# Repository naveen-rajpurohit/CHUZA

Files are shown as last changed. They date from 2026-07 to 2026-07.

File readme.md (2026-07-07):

<p align="center">
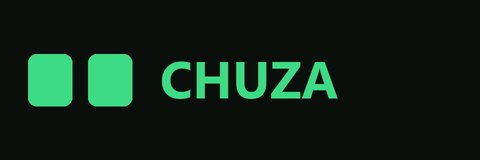
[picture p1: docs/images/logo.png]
CHUZA
  
</p>

<h3 align="center">An autonomous, internet-connected desktop companion robot</h3>

<p align="center">
  Built on an ESP32-S3 — animated OLED face, capacitive-touch reflexes, environmental sensing,<br>
  a globally-accessible FPV feed, and a custom desktop control app.
</p>

<p align="center">
  
  
  
  
</p>

---

CHUZA is more than an RC car — it's an autonomous desktop "pet" that wanders, reacts to petting, watches for the edge of the desk, and streams a live first-person video feed from anywhere in the world. This repo holds the full stack: the ESP32-S3 firmware, the wiring, and the companion desktop app used to drive it.

## Contents

- [Features](#features)
- [CHUZA Control (desktop app)](#chuza-control-desktop-app)
- [Architecture](#architecture)
- [Hardware & wiring](#hardware--wiring)
- [Tech stack](#tech-stack)
- [Getting started](#getting-started)
- [Repo structure](#repo-structure)
- [How it was built](#how-it-was-built)
- [License](#license)

## Features

- **Strictly non-blocking firmware.** `delay()` is banned throughout — a cooperative [`Scheduler`](lib/Scheduler/Scheduler.h) ticks every subsystem off `millis()`, so a slow network call can never make CHUZA miss a cliff edge.
- **Dual-core FreeRTOS split.** Core 0 owns WiFi, MQTT, and camera streaming; Core 1 owns motors, sensors, touch, and the display — heavy networking can never stall real-time control.
- **Animated RoboEyes-style face.** A mood engine on the SSD1306 OLED reacts to petting, battery level, and menu state (`lib/CHUZAFace`).
- **Capacitive touch gestures.** Single tap changes expression, triple tap opens the on-device menu — timing-based, debounced, tuned for the ESP32-S3's inverted touch polarity (`lib/CHUZATouch`).
- **Autonomous "Wander Mode".** Three intensities (OFF / SOFT / NORMAL) of idle-time exploration, instantly overridden by obstacle/cliff reflexes (`lib/CHUZAWander`).
- **Reflex safety.** Continuous VL53L0X polling for both forward obstacles and desk-edge "cliff" detection, clamped straight into the motor driver regardless of what's currently commanding it.
- **Dual connectivity, automatic failover.** A cloud path (TLS MQTT via HiveMQ) works from anywhere; the app auto-detects when it's on the same network as the robot and switches to a LAN-direct UDP + local MJPEG path for far lower latency (`lib/MqttLink`, `lib/CHUZALocalLink`).
- **Live FPV streaming.** The onboard OV2640 streams MJPEG over whichever transport is active, with a chip-thermal safety cutoff.
- **Persisted settings.** Every tunable (thresholds, PWM range, timers, per-subsystem enable/disable) lives in one `RobotSettings` model, editable from the app and saved to NVS.

## CHUZA Control (desktop app)

A Tkinter desktop app with a hand-rolled pixel-art "dark jungle" HUD — live telemetry, keyboard driving, and an in-app settings editor, all built directly on top of the same MQTT/UDP protocol the firmware speaks.

<table>
<tr>
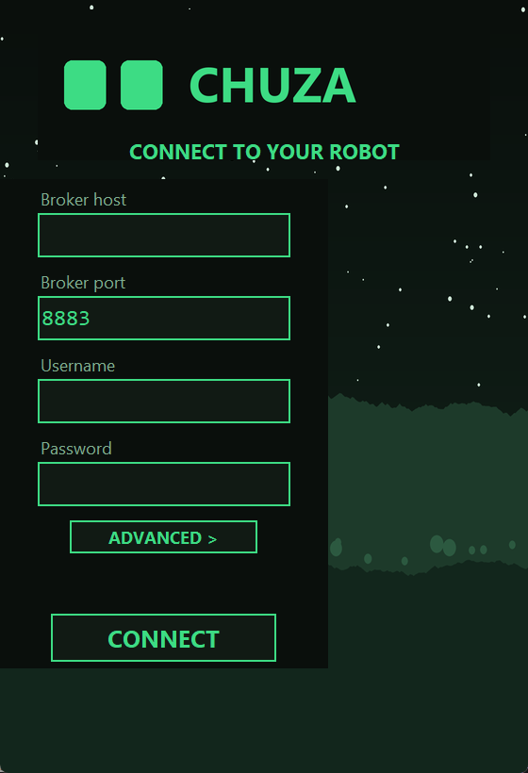
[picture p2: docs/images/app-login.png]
Login screen
<td align="center" width="50%"><br><sub>Connect screen — broker credentials, reused for in-app "Change Connection"</sub></td>
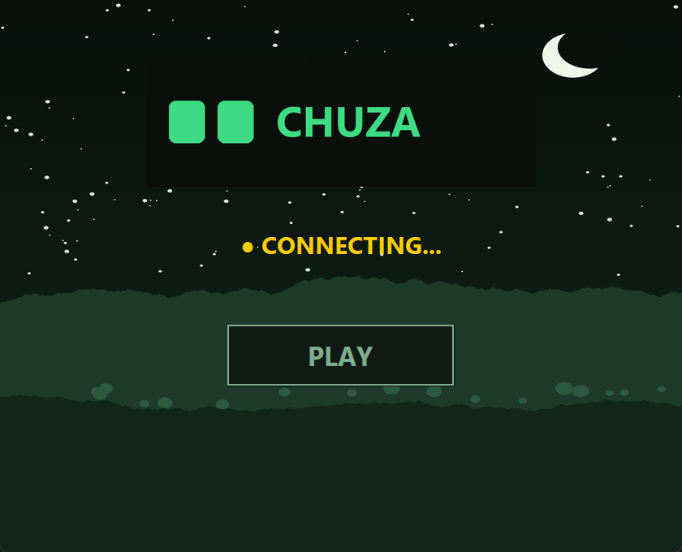
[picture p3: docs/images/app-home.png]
Home screen
<td align="center" width="50%"><br><sub>Home — live connection status, PLAY to enter driving mode</sub></td>
</tr>
<tr>
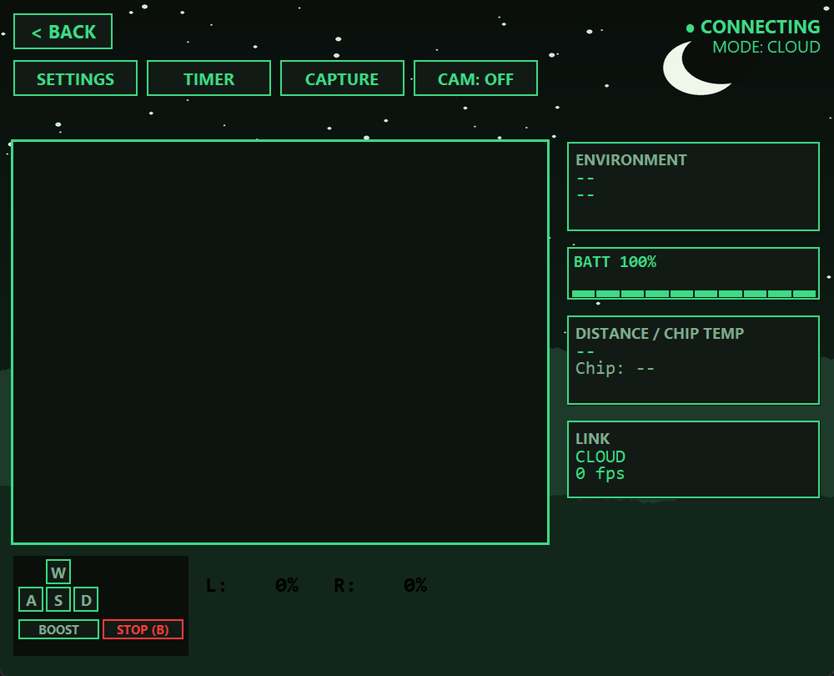
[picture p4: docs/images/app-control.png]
Control screen
<td align="center" width="50%"><br><sub>Control — camera viewport, D-pad readout, HUD telemetry sidebar</sub></td>
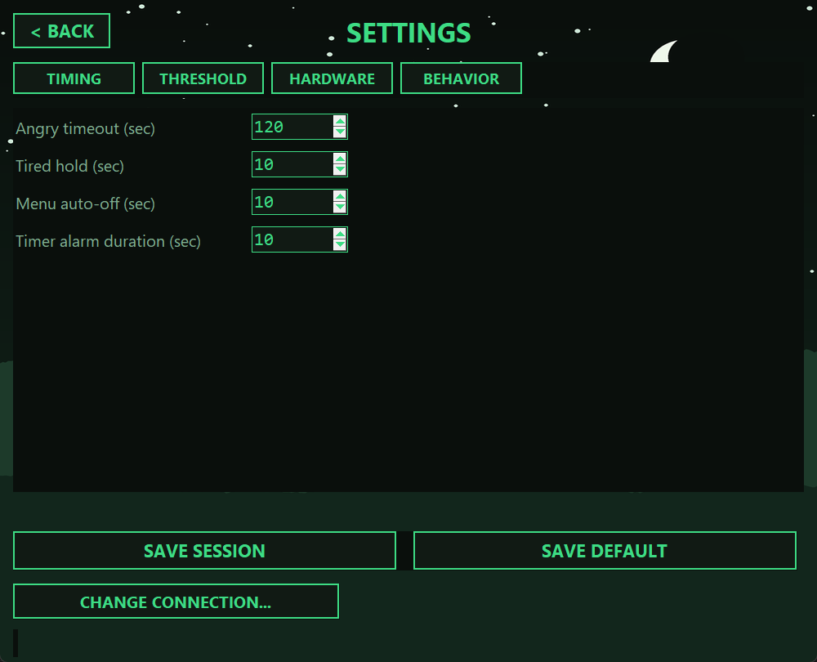
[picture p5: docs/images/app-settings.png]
Settings screen
<td align="center" width="50%"><br><sub>Settings — mirrors <code>RobotSettings</code> field-for-field, session or default save</sub></td>
</tr>
</table>

Driving uses **W/A/S/D** (Space to boost, B to brake), with gentle arc-turns while moving and pivot-turns while stationary. **CAPTURE** saves the current frame to disk; **TIMER** schedules an OLED alarm on the robot itself.

## Architecture

| Module | Responsibility |
|---|---|
| [`CHUZAWheels`](lib/CHUZAWheels) | DRV8833 motor driver — ramped speed targets, cliff-block clamp, per-side trim |
| [`CHUZAFace`](lib/CHUZAFace) | RoboEyes OLED face, mood engine, on-device menu state machine |
| [`CHUZATouch`](lib/CHUZATouch) | Debounced capacitive touch, single/double/triple-tap counting |
| [`CHUZABuzzer`](lib/CHUZABuzzer) | Non-blocking piezo melody/beep sequencer |
| [`CHUZAWander`](lib/CHUZAWander) | Autonomous idle-time driving policy (OFF/SOFT/NORMAL) |
| [`CHUZAEnvSense`](lib/CHUZAEnvSense) | BME280 temperature / humidity / pressure, cached reads |
| [`CHUZADistance`](lib/CHUZADistance) | VL53L0X time-of-flight ranging for obstacles + cliff edge |
| [`CHUZABattery`](lib/CHUZABattery) | Resistor-divider ADC read → 0–100% estimate |
| [`CHUZACamera`](lib/CHUZACamera) | OV2640 capture, enable/disable, thermal safety cutoff |
| [`CHUZASettings`](lib/CHUZASettings) | Single source of truth for every tunable, NVS persistence |
| [`MqttLink`](lib/MqttLink) | TLS MQTT over WiFi — two independent connections (commands, telemetry/camera) on Core 0 |
| [`CHUZALocalLink`](lib/CHUZALocalLink) | LAN-direct UDP commands + local MJPEG stream, always listening |
| [`CHUZACommand`](lib/CHUZACommand) | Single JSON command dispatcher shared by both MQTT and LAN-direct paths |
| [`Scheduler`](lib/Scheduler) | Minimal cooperative task scheduler driving the whole `loop()` |

**Command flow:** the app always tries LAN-direct UDP first; if that probe fails (different network, robot out of range), it transparently falls back to publishing on `robot/commands` over MQTT. Both paths route through the same `dispatchRobotCommand()`, so the robot behaves identically either way. Settings and timer commands are cloud-only, since the app's MQTT connection stays up regardless of link mode.

## Hardware & wiring

CHUZA wiring diagram

| Component | Role |
|---|---|
| Seeed XIAO ESP32S3 Sense | Main controller — dual-core ESP32-S3, WiFi, onboard OV2640 camera |
| DRV8833 | Dual H-bridge driver for the two drive motors |
| VL53L0X | Time-of-flight sensor — forward obstacles + downward cliff edge |
| BME280 | Temperature / humidity / pressure |
| SSD1306 (128×64, I2C) | Animated face / menu / clock display |
| Piezo buzzer | Non-blocking chirps and status tones |
| Capacitive touch pad | Petting input for the mood engine + menu access |
| LiPo cell + resistor divider | Power, with a halved-voltage tap into an ADC pin for battery %/voltage |

Pin assignments are centralized in [`include/CHUZAPins.h`](include/CHUZAPins.h) — nothing else in the codebase hardcodes a GPIO number. Two 3D-printed wheels (SolidWorks source + STL) live under [`Wheels/`](Wheels).

## Tech stack

**Firmware** — C++ / Arduino framework via PlatformIO, targeting `seeed_xiao_esp32s3`:
Adafruit BME280 / VL53L0X / SSD1306 / GFX / BusIO, PubSubClient, ArduinoJson.

**Desktop app** (`CHUZAControls/`) — Python 3, Tkinter for UI, `paho-mqtt` for the cloud link, Pillow for image handling, PyInstaller for standalone Windows builds.

## Getting started

### Firmware

1. Open the repo in [PlatformIO](https://platformio.org/) (VS Code extension or CLI).
2. Fill in your own values in [`include/Secrets.h`](include/Secrets.h) — WiFi credentials and a [HiveMQ Cloud](https://www.hivemq.com/mqtt-cloud-broker/) (or any TLS MQTT broker) host/username/password. The file is tracked as a template with placeholder values on purpose, so **never commit your real credentials over them**.
3. Build and upload to the `seeed_xiao_esp32s3` environment:
   ```
   pio run -t upload
   ```

### Desktop app

```
cd CHUZAControls
pip install -r requirements.txt
python app.py
```

On first launch, the login screen asks for the same broker host/username/password you put in `Secrets.h`. To build a standalone Windows executable instead, use the included `CHUZA Control.spec` with PyInstaller.

## Repo structure

```
CHUZA/
├── src/main.cpp            # setup()/loop() — wires every module together, owns the scheduler
├── include/CHUZAPins.h     # every GPIO assignment, in one place
├── include/Secrets.h       # WiFi + MQTT broker credentials (template — fill in your own)
├── lib/                    # one focused module per subsystem (see Architecture)
├── CHUZAControls/          # the Tkinter desktop control app
├── docs/images/            # README assets — screenshots, wiring diagram
└── Wheels/                 # 3D-printable wheel parts (SolidWorks + STL)
```

## How it was built

CHUZA V1 was built in six phases, each one only trusting the layer below it:

1. **Nervous system** — motor control, distance/cliff sensing, environmental sensing, non-blocking buzzer feedback.
2. **Face & touch** — animated OLED expressions, debounced capacitive tap timing, the on-device menu state machine.
3. **Brain** — fusing movement and UI into fully local, non-blocking autonomous behavior (Wander Mode + reflexes).
4. **Global communication** — NTP sync, TLS MQTT for bidirectional cloud control and telemetry.
5. **FPV streaming** — local MJPEG baseline first, then a LAN-direct UDP/HTTP path for low-latency same-network driving.
6. **Control hub** — the CHUZA Control desktop app, speaking the exact same command/telemetry protocol as the cloud and LAN paths.

## License

MIT — see [LICENSE](LICENSE).

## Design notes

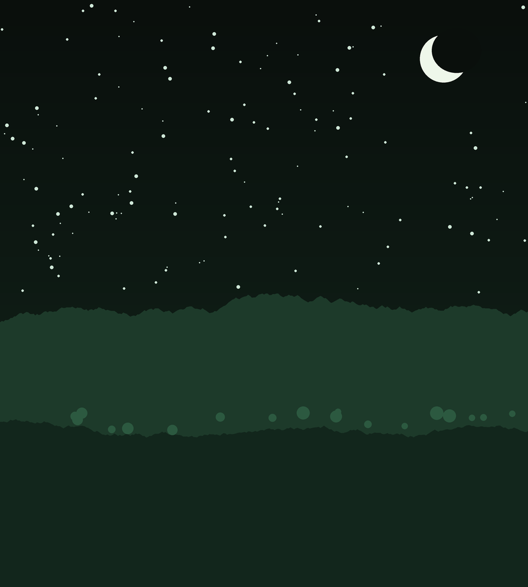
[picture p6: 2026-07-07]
CHUZAControls/assets/bg_jungle.png

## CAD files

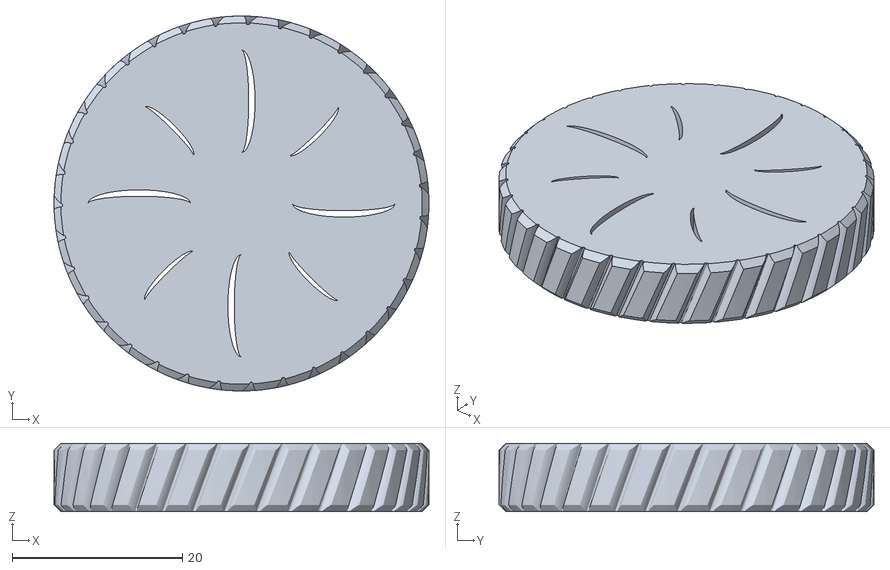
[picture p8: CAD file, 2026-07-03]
Wheels/wheel-r.STL
44.0 x 44.0 x 8.00

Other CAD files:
Wheels/wheel.SLDPRT
Wheels/wheel-l.SLDPRT
Wheels/wheel-l.STL

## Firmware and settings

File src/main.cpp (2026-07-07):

#include <Arduino.h>
#include "CHUZAPins.h"
#include "Secrets.h"
#include "CHUZAWheels.h"
#include "EnvSensor.h"
#include "BatterySensor.h"
#include "DistanceSensor.h"
#include "TouchSensor.h"
#include "Buzzer.h"
#include "CHUZAFace.h"
#include "CHUZACamera.h"
#include "MqttLink.h"
#include "CHUZALocalLink.h"
#include "Scheduler.h"
#include "WanderMode.h"
#include "RobotSettings.h"

CHUZAWheels wheels(PIN_LF, PIN_LB, PIN_RF, PIN_RB);
EnvSensor envSensor(PIN_SDA, PIN_SCL);
BatterySensor battery(PIN_BATT_SENSE);
DistanceSensor distanceSensor(PIN_SDA, PIN_SCL);
TouchSensor touchSensor(PIN_TOUCH);
Buzzer buzzer(PIN_BUZZER);
WanderMode wander;
CHUZAFace face(PIN_SDA, PIN_SCL, touchSensor, buzzer, envSensor, battery, distanceSensor, wander);
RobotSettings settings(wheels, face, touchSensor, buzzer, wander);

CameraPins camPins = {
    CAM_PIN_PWDN, CAM_PIN_RESET, CAM_PIN_XCLK, CAM_PIN_SIOD, CAM_PIN_SIOC,
    CAM_PIN_Y9, CAM_PIN_Y8, CAM_PIN_Y7, CAM_PIN_Y6, CAM_PIN_Y5, CAM_PIN_Y4, CAM_PIN_Y3, CAM_PIN_Y2,
    CAM_PIN_VSYNC, CAM_PIN_HREF, CAM_PIN_PCLK
};
CHUZACamera camera(camPins);

MqttLink mqttLink(wheels, envSensor, camera, battery, distanceSensor, face, settings);
CHUZALocalLink localLink(wheels, camera);
Scheduler scheduler;

void updateMotors() {
    wheels.update();
}

void updateEnvSensor() {
    if (settings.envSensorEnabled) envSensor.update();
}

void updateBattery() {
    battery.update();
}

void updateDistance() {
    if (!settings.distSensorEnabled) {
        wheels.setCliffBlocked(false); // no sensor feeding it - don't leave a stale block in place
        return;
    }
    distanceSensor.update();
    wheels.setCliffBlocked(distanceSensor.getDistanceMm() > settings.cliffThresholdMm);
}

void updateFace() {
    face.update();
}

void updateBuzzer() {
    buzzer.update();
}

void updateWander() {
    wander.update(wheels);
}

void setup() {
    Serial.begin(115200);

    randomSeed(esp_random()); // so WanderMode's bursts aren't the same sequence every boot

    wheels.begin();

    if (!envSensor.begin()) {
        Serial.println("BME280 not found - check wiring/I2C address");
    }

    if (!distanceSensor.begin()) {
        Serial.println("VL53L0X not found - check wiring/I2C address");
    }

    battery.begin();
    touchSensor.begin();
    buzzer.begin();

    if (!face.begin()) {
        Serial.println("OLED not found - check wiring/I2C address");
    }

    if (!camera.begin()) {
        Serial.println("Camera init failed - check the Sense board/ribbon cable");
    }

    // Loads last-saved-as-default values from NVS (or the hardcoded
    // defaults on first boot) and pushes them into wheels/face/touch/
    // buzzer/wander - must run after all of those begin() calls above.
    settings.begin();

    delay(2000);

    mqttLink.begin(WIFI_SSID, WIFI_PASSWORD,
                   MQTT_HOST, MQTT_PORT,
                   MQTT_USERNAME, MQTT_PASSWORD,
                   MQTT_CLIENT_ID);

    // WiFi should be up by now (mqttLink.begin() blocks for it above) -
    // configTime() queues an NTP sync in the background; CHUZAFace's
    // clock menu page reads the result via getLocalTime().
    configTime(TIMEZONE_OFFSET_SEC, 0, NTP_SERVER);

    // Runs on its own core (0): commands, telemetry, and camera frames
    // all happen there, fully independent of the scheduler below - see
    // the class comment on MqttLink for why this is a single task.
    mqttLink.startNetworkTask();

    // LAN-direct fallback: the app auto-switches to this (UDP commands +
    // local MJPEG stream) whenever it's on the same network as the
    // robot, for far lower latency and higher fps than the cloud path.
    localLink.begin();

    scheduler.addTask(updateMotors, 10);     // motor ramp tick, every 10ms
    scheduler.addTask(updateEnvSensor, 50);  // BME280 sample tick, every 50ms
    scheduler.addTask(updateBattery, 500);   // battery voltage tick, every 500ms
    scheduler.addTask(updateDistance, 100);  // VL53L0X ranging tick, every 100ms
    scheduler.addTask(updateFace, 33);       // touch + eyes/menu tick, ~30fps
    scheduler.addTask(updateBuzzer, 5);      // buzzer note/gap timing tick, tight for clean beeps
    scheduler.addTask(updateWander, 10);     // wander dice-roll + burst timing tick, same cadence as the motor ramp
}

void loop() {
    scheduler.run();
}

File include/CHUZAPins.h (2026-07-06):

#pragma once

// --- CHUZA V1 Pin Map ---
// Every pin on the robot lives here. As sensors / display / camera /
// wifi peripherals come online, add their pins below instead of
// scattering #define's through main.cpp or other modules.

// CHUZAWheels (Motor_Driver)
#define PIN_LF   D9
#define PIN_LB   D10
#define PIN_RF   D0
#define PIN_RB   D6

// I2C bus (BME280 environmental sensor, VL53L0X time-of-flight distance
// sensor, and anything else on the bus)
#define PIN_SDA  D4
#define PIN_SCL  D5

// Battery voltage sense: midpoint of a resistor divider across the
// battery, read on an ADC-capable pin. The divider halves the battery
// voltage before it reaches this pin, so BatterySensor doubles the
// reading back out.
#define PIN_BATT_SENSE D2

// Capacitive touch pad (petting sensor) for CHUZAFace's mood engine and
// menu navigation. Any GPIO1-14 works for touch on the ESP32-S3; D1 was
// free.
#define PIN_TOUCH D1

// Piezo buzzer for CHUZAFace's beeps/jingles (touch chirps, mood/menu/
// stopwatch/timer events).
#define PIN_BUZZER D8

// Onboard OV2640 camera (XIAO ESP32S3 Sense). Fixed silicon routing on
// the Sense sensor board — these are GPIO numbers, not D-pin aliases,
// and don't overlap with the D-pins used above.
#define CAM_PIN_PWDN     -1
#define CAM_PIN_RESET    -1
#define CAM_PIN_XCLK     10
#define CAM_PIN_SIOD     40
#define CAM_PIN_SIOC     39
#define CAM_PIN_Y9       48
#define CAM_PIN_Y8       11
#define CAM_PIN_Y7       12
#define CAM_PIN_Y6       14
#define CAM_PIN_Y5       16
#define CAM_PIN_Y4       18
#define CAM_PIN_Y3       17
#define CAM_PIN_Y2       15
#define CAM_PIN_VSYNC    38
#define CAM_PIN_HREF     47
#define CAM_PIN_PCLK     13

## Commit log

2026-06-25 Added Wheels
    [wheel-l.SLDPRT, wheel.SLDPRT]
2026-07-03 Proj Checkpoints
    [wheel-l.STL, wheel-r.STL]
2026-07-03 basic motor controls
2026-07-04 Finalized Motors with Scheduler
2026-07-06 Added Battery% and ToF Sensor
2026-07-06 Oled Display + Buzzer + Menu
    [CHUZAPins.h, main.cpp]
2026-07-07 Polish repo for public release: README, LICENSE, diagram, screenshots
    Rewrites readme.md to document the finished V1 architecture (module
    table, wiring diagram, app screenshots, setup instructions) instead of
    the original forward-looking roadmap. Adds an MIT LICENSE, a wiring
    diagram generated from CHUZAPins.h, and CHUZA Control app screenshots
    under docs/images/. Removes leftover PlatformIO scaffold READMEs, and
    fixes config.json's template values to actually trip the app's
    placeholder-detection (REPLACE_ME) so a fresh clone lands on the login
    screen instead of silently trying to connect with garbage credentials.
2026-07-08 modified: include/Secrets.h modified: lib/CHUZABattery/BatterySensor.h
2026-07-12 Add CHUZAWeb: browser control app for iPhone
    A new, purely additive static PWA (CHUZAWeb/) that lets the robot be
    driven from a phone browser without touching firmware or the existing
    desktop app - it speaks the same MQTT command/telemetry protocol as
    CHUZAControls, just over MQTT-over-WebSockets (HiveMQ Cloud's port
    8884) instead of raw TLS, since browsers can't open raw TLS sockets or
    UDP. Deployed via a new GitHub Actions workflow to GitHub Pages.
2026-07-12 Remove auto-generated static.yml Pages workflow
    GitHub's Pages setup UI created this as a starter template alongside
    the already-existing deploy-chuzaweb.yml. It deploys the whole repo
    root (path: '.') instead of CHUZAWeb/, and since it triggers on every
    push to main (no path filter) it was overwriting the correct
    CHUZAWeb-only deployment - the site root has no index.html, hence the
    404. deploy-chuzaweb.yml is the one correctly-scoped workflow.
